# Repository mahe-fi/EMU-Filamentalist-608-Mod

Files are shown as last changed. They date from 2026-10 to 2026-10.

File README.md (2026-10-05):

 # EMU Filamentalist – 608 bearing mod

> [!IMPORTANT]
> **This is an unofficial mod for [EMU – Expandable Multi-material Unit](https://github.com/DW-Tas/EMU)** by DW-Tas and igiannakas.
> All parts here are **derived from the original EMU models** in that repository. Only the parts that had to change for this mod are included. Everything else comes from the original project.
> Please refer to the [original repository](https://github.com/DW-Tas/EMU) for the full documentation, BOM, assembly manuals and videos, and the printed parts configurator ([emu.dwtas.net](https://emu.dwtas.net)).

The stock EMU Filamentalist lane uses five **688** bearings (8×16×5 mm). This mod replaces them with five **608** bearings (8×22×7 mm). 608s are the common skateboard bearing: cheap, widely available and more robust.

## What changes

Per lane, all five 688 bearings are replaced with 608s:

| Location | Bearings | How it was adapted |
|---|---|---|
| Wheel (rim roller) axle | 2 | The inner faces of the bearings stay where they were, so the gap between the two bearings, the one-way bearing, the drive roller (CDR) and the stepper body are unchanged. Each bearing grows 2 mm outward. |
| Idler roller axle | 2 | Same as the wheel axle. The idler roller axle is unchanged. |
| Filamentalist tensioner arm | 1 | The bearing centre moved 3 mm straight away from the CDR, so the pinch gap against the TPU ring is unchanged. |

To make room while keeping the **overall width of the lane unchanged**:

- **Chassis L/R:** new bearing bosses and crush-rib pockets for 22 mm bearings. The four chassis-to-stepper M3 countersunk screws next to the idler bearings moved 2.5 mm outward, because the original screw heads would hit the new bores.
- **Stepper main body:** the four matching heat-set insert pockets moved 2.5 mm outward. The body outline around the idler is extended to match the enlarged chassis plates.
- **Rim rollers and idler rollers:** 2 mm narrower each, taken off the bearing side, so the outer faces of the lane stay in the same place.
- **Tensioner arm:** wider (7 mm) bearing slot, open straight up so the bearing drops in. The flat top face is raised 3 mm for enough wall around the countersunk axle screw.
- **Tensioner mount:** the nose next to the bearing is trimmed about 2 mm, so the larger bearing clears it over the full arm travel.
- **Bushing:** lengthened from 5 mm to 7 mm.
- **LED holder:** raised 4.5 mm to clear the taller tensioner arm, with an added spacer strip underneath that seats on the chassis/stepper as before. The Neopixel PCB moves up with it.

## Hardware changes vs. stock EMU (per lane)

| Stock | This mod | Qty | Notes |
|---|---|---|---|
| 688 bearing (8×16×5 mm) | **608 bearing (8×22×7 mm)** | 5 | Use 2RS/ZZ shielded bearings |
| M3×8 FHCS (LED holder to stepper body) | **M3×12 FHCS** | 1 | The LED holder sits 4.5 mm higher |
| Rim roller rubber band, 23 mm wide | **Rubber band, 21 mm wide** | 2 | See below |

> [!IMPORTANT]
> **A narrower rubber band is needed on the rim rollers.** The band seat on the rim rollers is 2 mm narrower than stock: **21 mm instead of 23 mm**. Inner diameter (~63 mm) and thickness (~1.5 mm) are unchanged. Use a band of the same size as stock, but 21 mm wide, or trim a stock band to 21 mm.

All other hardware is the same as stock EMU. Refer to the original [BOM and sourcing guide](https://github.com/DW-Tas/EMU/blob/main/docs/sourcing.md).

## Files

```
CAD/   EMU_Filamentalist608.step   – full Filamentalist lane assembly with the mod applied
STL/   modified printed parts only
EMU_Filamentalist608.FCStd          – FreeCAD source of the modified Filamentalist lane assembly
```

> [!NOTE]
> **Only modified parts are exported as STLs.** Print all other parts from the original [EMU repository](https://github.com/DW-Tas/EMU) or its [configurator](https://emu.dwtas.net).

STL files follow the original EMU naming convention: **`[a]_` prefix = accent colour part** (red in the CAD model). Parts without the prefix are printed in the primary colour. An **`_x2`** suffix means print two.

| STL | Colour | Replaces original part | Qty | Print notes |
|---|---|---|---|---|
| `Chassis_L_608_Bearing001.stl` | Primary | Chassis_L_688_Bearing | 1 | |
| `Chassis_R_608_Bearing001.stl` | Primary | Chassis_R_688_Bearing | 1 | |
| `Stepper_Main_Body001.stl` | Primary | Stepper_Main_Body | 1 | |
| `EMU_Tensioner_Mount_with_Sensor001.stl` | Primary | EMU_Tensioner_Mount_with_Sensor | 1 | |
| `LED_holder001.stl` | Primary | LED_holder | 1 | **Print lying on its side.** The spacer strip's ends are tapered at 45° so there are no unsupported ledges in that orientation. The file contains two overlapping shells (holder + spacer strip); slicers merge them automatically. |
| `[a]_Rim_Roller_EMU_x2.stl` | Accent | [a]_Rim_Roller_EMU_x2 | **2** | Same part on both sides of the lane, so print 2 |
| `[a]_Idler_Roller_x2.stl` | Accent | [a]_Idler_Roller_x2 | **2** | Same part on both sides of the lane, so print 2 |
| `[a]_Tensioner_Arm001.stl` | Accent | [a]_Tensioner_Arm | 1 | **Print with the large flat top face on the build plate**, no supports needed |
| `[a]_608_Bearing_Bushing001.stl` | Accent | 688_Bearing_Bushing | 1 | 7 mm long (stock 5 mm) |

The STLs are positioned in assembly coordinates, so place them on the build plate in your slicer.

## Print settings

> [!IMPORTANT]
> **Some parts require supports** The built in supports in tensioner mount and stepper main body did not survive modding. Until they're added back to STLs, use slicer supports.

Use the same print settings as the original EMU. The section below is **copied verbatim from the original EMU documentation** ([Printing, Assembly and Wiring](https://github.com/DW-Tas/EMU/blob/main/docs/assembly_wiring/README.md#print-settings)). All credit to the EMU authors.

The parts in this mod are Filamentalist and lane stepper components, so the first subsection applies. The dry box and base unit settings are reproduced for completeness.

---

> [!WARNING]
> **Parts are not shrinkage compensated** - calibrate your filament shrinkage first! 

### Filamentalist components and Lane stepper components:
The below print settings are recommended for the filamentalist and lane stepper components. These are structural parts hence require print settings optimised for strength:
- 0.2 mm layer height
- 0.2 mm first layer height
- 4 walls
- 40% infill
- 0.4mm extrusion width (line width) throughout
- Gyroid sparse infill is recommended as it tends to warp less
- Inner Outer wall ordering, to ensure overhangs and supported areas do not sag
- Arachne wall generator
- One wall top and bottom surfaces (optional but recommended - parts look nicer)
- Disable thick bridges
- Z hop enabled to avoid nozzle scraping (0.2 is sufficient)

> [!IMPORTANT]
> If the bearings are loose, you're either under extruding, or over compensating for shrinkage.<br/>

> [!IMPORTANT]
> The [Idler_Roller_Axle](https://github.com/DW-Tas/EMU/blob/main/STL/Filamentalist/Idler_Roller_Axle.stl) and [[a]_Stepper_Tension_Arm](https://github.com/DW-Tas/EMU/blob/main/STL/Stepper/%5Ba%5D_Stepper_Tension_Arm%5BMR693zz%5D.stl) are best to be printed with **999 walls** to ensure adequate strength of the part and less chance of breakage.

> [!IMPORTANT]
> **Disable thick bridges** in your slicer and make sure your flow rate (EM) is on point! **Over extrusion, thick bridges and insufficient cooling will cause your sensor magnets and bearings not to fit as the bridges will sag.**

**For the TPU filamentalist CDR ring:**
- 0.2 mm layer height
- 0.2 mm first layer height
- 0.4mm extrusion width (line width) throughout
- 6 walls, so that the object is printed solid
- Avoid crossing walls enabled
- Random seam. This is important to avoid an aligned seam bump
- Inner Outer wall ordering, to ensure overhangs and supported areas do not sag
- Z Hop turned off to reduce stringing
  
> [!IMPORTANT]
> Printing TPU can be a challenge - print by object and a slight negative (-0.1) extra length on retract can help reduce stringing.

### Dry Box components:
The below print settings are recommended for the dry boxes and the desiccant holder. The dry boxes need to be as air tight as possible, hence the recommended print settings below are tuned to achieve this while keeping filament use under control.
- 0.2 mm layer height
- 0.2 mm first layer height
- 3 walls
- 15% infill
- For the lid specifically, use 4 walls and 30% infill to ensure strength in the front lip.
- 0.4mm extrusion width (line width) throughout
- Gyroid sparse infill is recommended as it tends to warp less
- Inner Outer wall ordering, to ensure dry box hatch features print with minimal sagging.
- Arachne wall generator
- One wall top and bottom surfaces (optional but recommended - parts look nicer)
- Disable thick bridges
- Z hop enabled to avoid nozzle scraping (0.2 is sufficient)

> [!IMPORTANT]
> Print with **extra first layer squish, use an adhesion promoter on the bed and in a pre-heated chamber with low fan** to prevent warping and ensure better layer adhesion. Mouse ears on the box corners may be required. Slight lifting will not impact part function.<br/>
> **Do not use mouse ears on the lid** as the slicer wrongly fills in the aesthetic lines.<br/>
> **Over extrude (only) the box and lid by ~2% (0.02)** to ensure air tightness. Increase your slicer flow multiplier (EM) by 0.02.

### Base unit components:
The below print settings are recommended for the base units and their accessories. 
- 0.2 mm layer height
- 0.2 mm first layer height
- 3 walls
- 15% infill
- 0.4mm extrusion width (line width) throughout
- Gyroid sparse infill is recommended as it tends to warp less
- Inner Outer Inner wall ordering to improve visual appearance
- Arachne wall generator
- One wall top and bottom surfaces (optional but recommended - parts look nicer)
- Disable thick bridges
- Z hop enabled to avoid nozzle scraping (0.2 is sufficient)
- For the **Eject button lens, 99 walls are recommended,** to reduce possibility of infill shining through the natural ABS

> [!IMPORTANT]
> Print with **extra first layer squish, use an adhesion promoter on the bed and in a pre-heated chamber with low fan** to prevent warping. Slight lifting will not impact part function.

> [!NOTE]
> **Paint on fuzzy skin** on the outer walls of the base unit will improve appearance.<br/>
> Paint on ONLY, not full model fuzzy skin. <br/>
> 0.1 distance, 0.1 or 0.2mm depth. Displacement method (orca slicer)

---

### Additional notes for this mod

- **608 bearing fit:** the new bearing pockets use the same crush-rib style as the original 688 pockets, scaled for 22 mm. The same advice applies: if the bearings are loose, you're under extruding or over-compensating for shrinkage.
- **Tensioner arm:** print with the large flat top face down. The bearing slot is open toward that face, so the 608 drops straight in.
- **LED holder:** print lying on its side.

## Assembly

Assemble as per the original EMU [assembly manuals and videos](https://github.com/DW-Tas/EMU/blob/main/docs/assembly_wiring/README.md). Differences:

1. Press 608 bearings into the chassis bosses (2 per chassis plate) and into the tensioner arm (with the 7 mm bushing).
2. Fit the narrower (21 mm) rubber bands on the rim rollers.
3. Use an M3×12 FHCS instead of M3×8 to fix the LED holder to the stepper body.

## License

The original EMU is licensed under the [Creative Commons Attribution-NonCommercial-ShareAlike 4.0 International License](https://creativecommons.org/licenses/by-nc-sa/4.0/). As a derivative work, **this mod is distributed under the same CC BY-NC-SA 4.0 license**. Credit for the original design goes to DW-Tas, igiannakas and the EMU contributors. EMU itself builds on the Filamentalist V3 design.

This is an unofficial community mod and is not endorsed by or affiliated with the EMU authors.

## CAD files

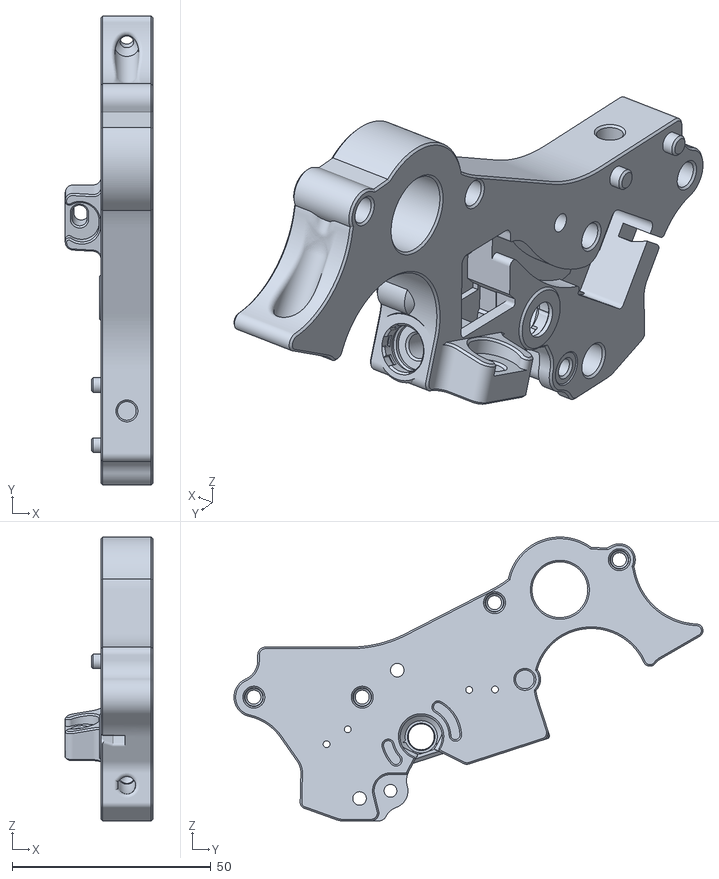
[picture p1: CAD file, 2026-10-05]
STL/Stepper_Main_Body001.stl
22.0 x 117.9 x 71.4

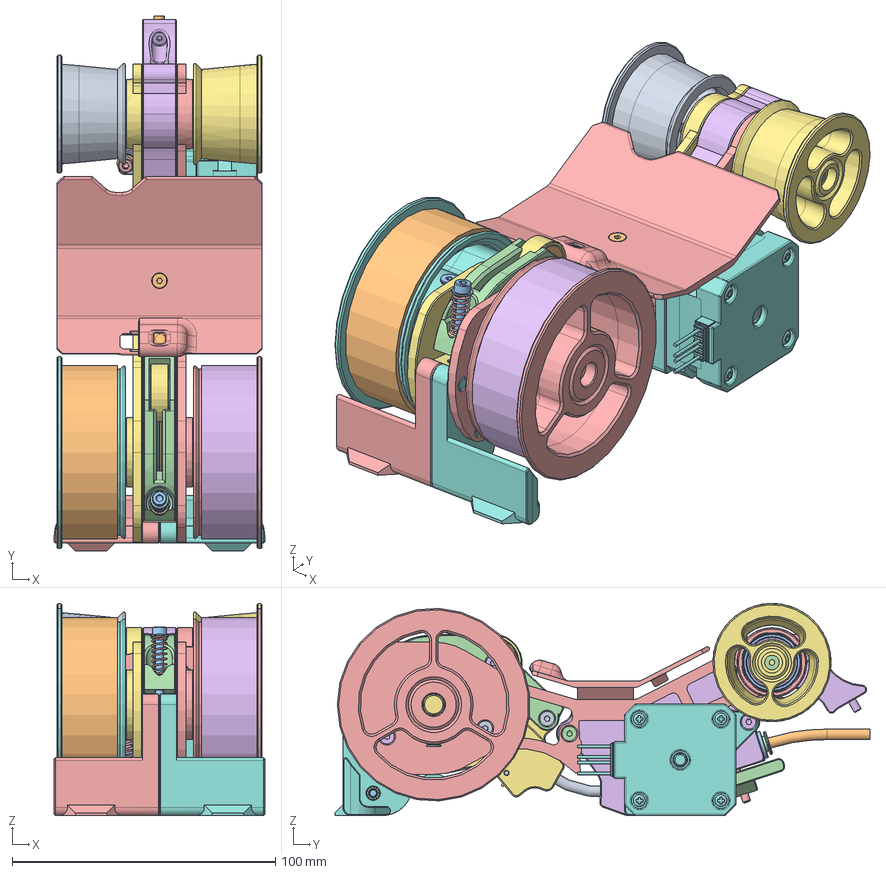
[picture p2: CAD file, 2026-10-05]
EMU_Filamentalist608.FCStd
80.0 x 203.2 x 80.6 mm
Hex socket countersunk head screw M3x0.5 x 051
Hex socket countersunk head screw M3x0.5 x 052
Hex socket countersunk head screw M3x0.5 x 053
Hex socket countersunk head screw M3x0.5 x 054
Idler_Roller_Axle001
Hex socket countersunk head screw M3x0.5 x 055
EMU_Tensioner_Mount_with_Sensor001
Hex socket countersunk head screw M3x0.5 x 056
[a]_Idler_Roller_x004
Hex socket countersunk head screw M3x0.5 x 057
Square thin nut grade B M3x0.015
[a]_608_Bearing_Bushing001
M3 Threaded Insert039
M3 Threaded Insert040
[a]_Idler_Roller_x005
M3 Threaded Insert041
Hex socket countersunk head screw M3x0.5 x 058
Neopixel Mini Button PCB003
Hex socket head cap screw M3x0.50 x 032
[a]_Tensioner_Arm001
LED_holder001
Hex socket countersunk head screw M3x0.5 x 059
Hex socket head cap screw M2x0.40 x 016
Hex socket countersunk head screw M3x0.5 x 060
Hex socket head cap screw M2x0.40 x 017
Rubber_Band(Mirror)002
Plain washer normal grade C M007
1-Way_Bearing001
6x0.6x15mm Spring v002
Rubber_Band(Mirror)003
Wheel axle v002
[TPU]_Half_Ring_Flex_1.65mm_x2 v002
[a]_CDR001
[TPU]_Half_Ring_Flex_1.65mm_x2 v003
Hex socket countersunk head screw M3x0.5 x 061
Hex socket countersunk head screw M3x0.5 x 062
[a]_Rim_Roller_EMU_x004
Hex socket countersunk head screw M3x0.5 x 063
Plain washer normal grade C M008
[a]_Rim_Roller_EMU_x005
Hex socket countersunk head screw M3x0.5 x 064
M3 Threaded Insert042
Hex socket countersunk head screw M3x0.5 x 065
Hex socket countersunk head screw M3x0.5 x 066
Hex socket countersunk head screw M3x0.5 x 067
Square thin nut grade B M3x0.016
Chassis_R_608_Bearing001
[a]_BME280_Holder001
SC70-6-1-solid002
Switch Body010
Contacts015
Plunger005
Lever003
Contacts016
Contacts017
Magnet 6x006
Switch Body011
M3 Threaded Insert043
Hex socket countersunk head screw M3x0.5 x 068
Chassis_L_608_Bearing001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

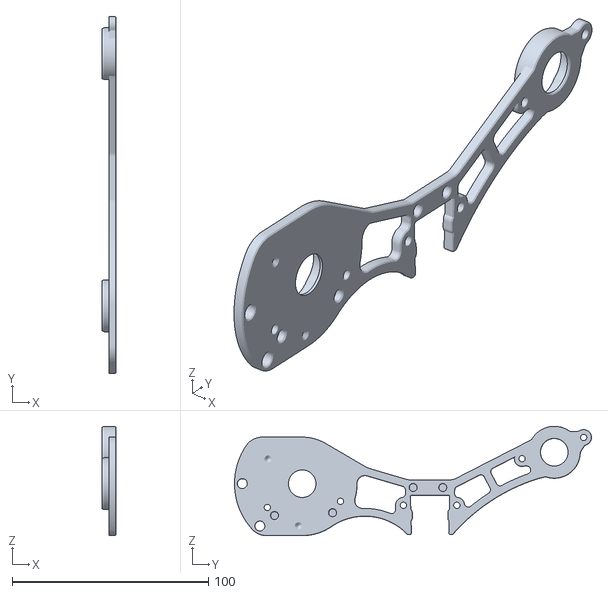
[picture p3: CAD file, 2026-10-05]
STL/Chassis_R_608_Bearing001.stl
7.00 x 181.9 x 55.8

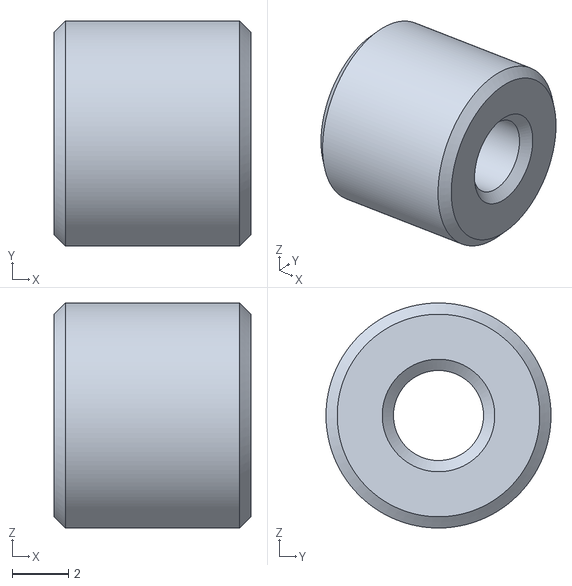
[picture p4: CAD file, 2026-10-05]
STL/[a]_608_Bearing_Bushing001.stl
7.00 x 8.00 x 8.00

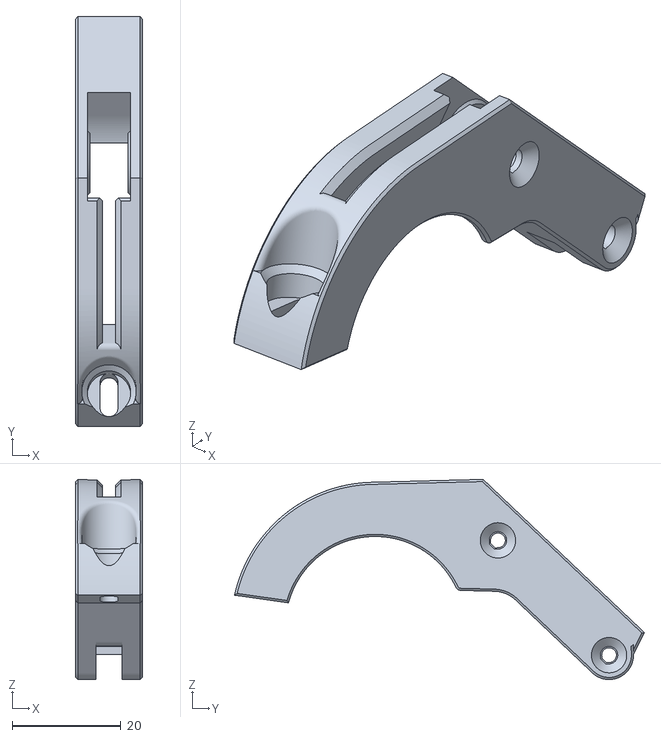
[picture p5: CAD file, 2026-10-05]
STL/[a]_Tensioner_Arm001.stl
12.3 x 75.5 x 36.8

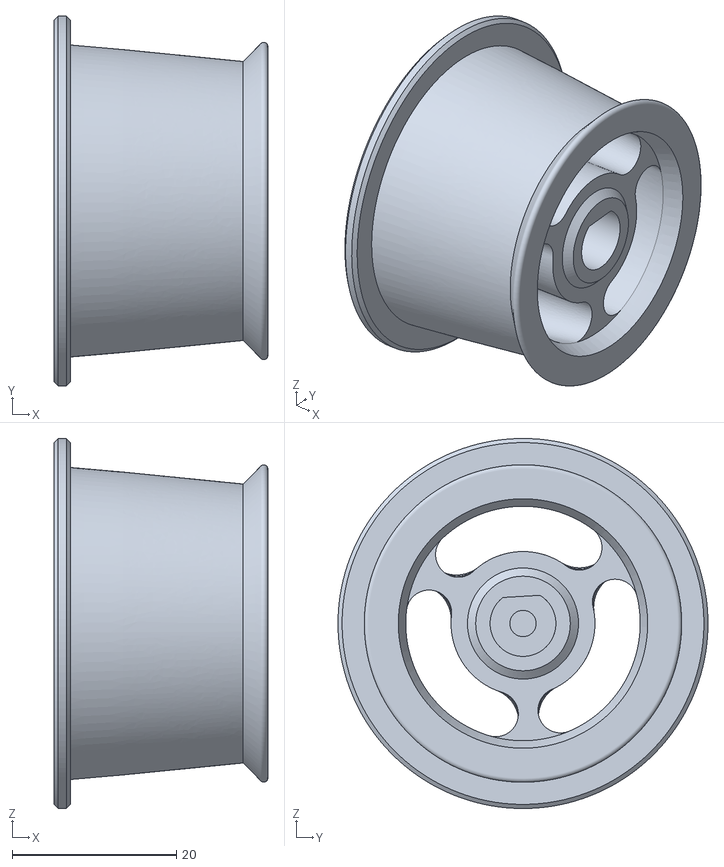
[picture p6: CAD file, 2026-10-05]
STL/[a]_Idler_Roller_x2.stl
26.0 x 45.0 x 45.0

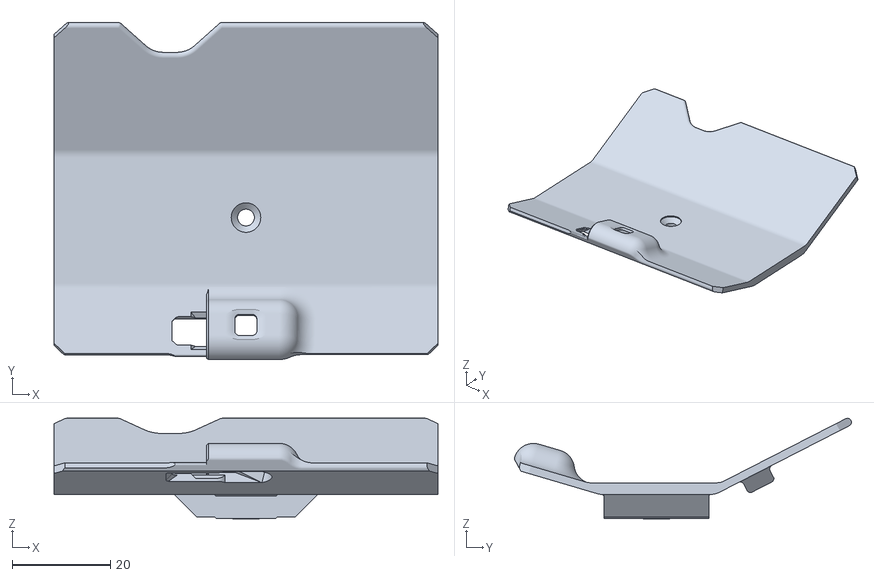
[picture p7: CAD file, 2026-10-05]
STL/LED_holder001.stl
78.0 x 68.5 x 20.4

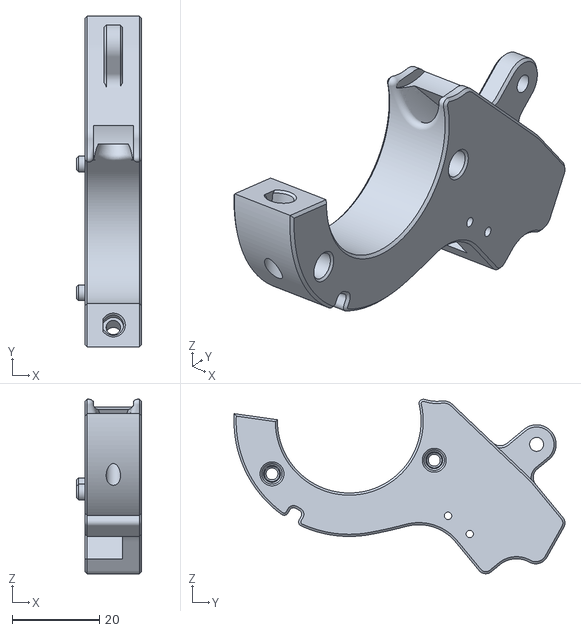
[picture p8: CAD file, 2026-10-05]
STL/EMU_Tensioner_Mount_with_Sensor001.stl
15.0 x 76.1 x 40.1

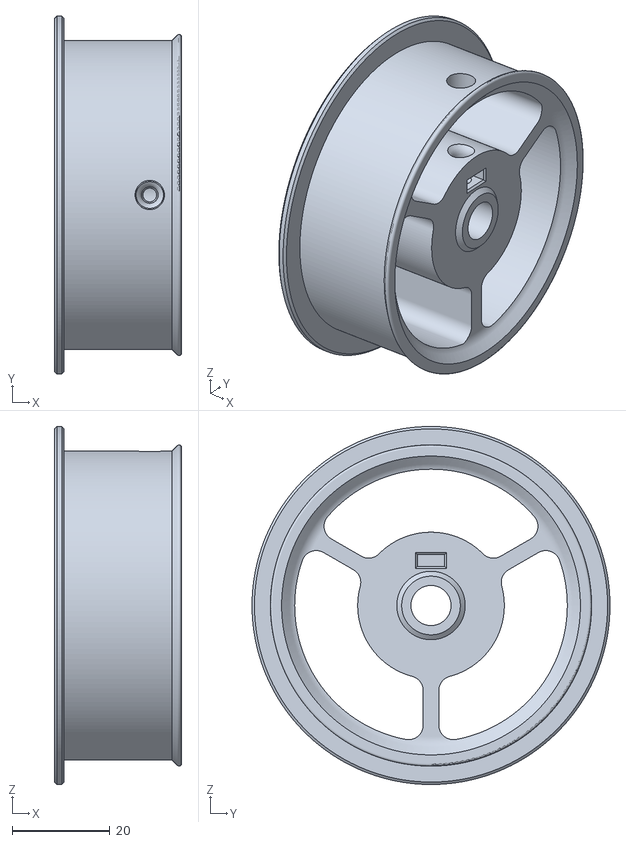
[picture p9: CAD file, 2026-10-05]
STL/[a]_Rim_Roller_EMU_x2.stl
26.0 x 73.2 x 73.2

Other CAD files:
STL/Chassis_L_608_Bearing001.stl

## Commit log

2026-10-05 Filamentalist assembly from EMU modified for 608 bearings. README, LICENCE for publishing in github
    [Chassis_L_608_Bearing001.stl, Chassis_R_608_Bearing001.stl, EMU_Filamentalist608.FCStd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]
2026-10-05 Update README.md
    Add support disclaimer to Print Settings
